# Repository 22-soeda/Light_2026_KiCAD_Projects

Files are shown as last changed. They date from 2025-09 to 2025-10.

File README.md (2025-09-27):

2026 ３月のROBO-ONE light 向けの回路CAD

工大祭(2025 11月頭)に向けて
 - main esp32e can
   - esp32とPCをwifiで接続して、GUIでロボットをデバッグ
   - Serial2をTTL変換して、zhコネクタで6ポート出力
   - 7.4VDCDC,12V 強電の系をまとめてスイッチング
   - canを2ポート搭載
   - 終端抵抗はブリッジで選択
   - BNO055はUART(Serial1)で実装
   - 5V reg, 3.3V DCDCを搭載
 - FSR to can
   - ATmega328P-AUをマイコンとする
   - 外部16MHz
   - FSRのシグナルをRail to Rail OPAMPで増幅、アナログ値を読み取り(4ポート)
   - MCP2515、MCP2561でcanを実装
   - 12V電源入力で、5Vregで降圧

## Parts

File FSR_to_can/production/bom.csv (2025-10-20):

Designator | Footprint | Quantity | Value | LCSC Part #
C1, C2 | 0805 | 2 | 0.1u
C3, C4 | 0805 | 2 | 1u
C5 | 0805 | 1 | 4.7u
C6 | 0805 | 1 | 10u
C7 | 0805 | 1 | 22u
C8 | 0805 | 1 | 0.1uF
D1 | 0603 | 1 | SCK
D2 | 0603 | 1 | power
J1 | JST_ZH_S5B-ZR-SM4A-TF_1x05-1MP_P1.50mm_Horizontal | 1 | FSR_socket
J2 | JST_ZH_B5B-ZR_1x05_P1.50mm_Vertical | 1 | write
J3 | JST_ZH_B6B-ZR_1x06_P1.50mm_Vertical | 1 | boot
J4 | JST_XH_S2B-XH-A_1x02_P2.50mm_Horizontal | 1 | power_socket
J5 | JST_ZH_S2B-ZR-SM4A-TF_1x02-1MP_P1.50mm_Horizontal | 1 | can_socket
JP1 | SolderJumper-2_P1.3mm_Open_RoundedPad1.0x1.5mm | 1 | Term
R1, R2, R3, R4, R5, R6, R7 | 0603 | 7 | 1k
R10, R11, R12, R9 | 0603 | 4 | R
R8 | 0603 | 1 | 120
SW1 | TVAF06-A020B-R | 1 | SW_Push
U1 | TQFP-32_7x7mm | 1 | ATMEGA328P-AU | ATMEGA328P-AU
U2 | SOT-223-3_TabPin2 | 1 | AMS1117-5.0
U3 | TSSOP-20_4.4x6.5mm_P0.65mm | 1 | MCP2515-xST
U4 | SOIC-8_3.9x4.9mm_P1.27mm | 1 | MCP2561-E-SN
U5, U6 | SOIC-8_W3.9mm | 2 | LMV358IDR | LMV358IDR
Y1 | Resonator_SMD_Murata_CSTxExxV-3Pin_3.0x1.1mm_HandSoldering | 1 | 16MHz
Y2 | Resonator_SMD_Murata_CSTxExxV-3Pin_3.0x1.1mm_HandSoldering | 1 | 8MHz

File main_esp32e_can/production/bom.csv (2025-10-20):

Designator | Footprint | Quantity | Value | LCSC Part #
C1 | 0805 | 1 | 22u
C10 | CP_Elec_6.3x5.9 | 1 | 100u
C11 | CP_Elec_5x5.8 | 1 | 10u
C12 | CP_Elec_6.3x5.9 | 1 | 22u
C13, C18 | 0805 | 2 | 10u
C14, C16, C19, C2, C21, C3, C4, C5, C6, C9 | 0805 | 10 | 0.1u
C15, C20 | 0805 | 2 | 33u
C17, C22 | 0805 | 2 | 47u
C7 | CP_Elec_10x12.6 | 1 | 470u
C8 | 0805 | 1 | 0.33u
D1 | 0603 | 1 | LED_motor
D2 | 0603 | 1 | LED_logic
J1 | JST_ZH_B6B-ZR_1x06_P1.50mm_Vertical | 1 | write_socket
J10, J11 | JST_XA_B02B-XASK-1_1x02_P2.50mm_Vertical | 2 | 12Vout
J12 | AMASS_XT60-M_1x02_P7.20mm_Vertical | 1 | Batt_socket
J13 | JST_XA_B02B-XASK-1-A_1x02_P2.50mm_Vertical | 1 | SW_strong
J14 | JST_XH_B2B-XH-AM_1x02_P2.50mm_Vertical | 1 | LED_strong
J15 | JST_XH_B2B-XH-AM_1x02_P2.50mm_Vertical | 1 | LED_logic
J16 | JST_XA_B02B-XASK-1-A_1x02_P2.50mm_Vertical | 1 | SW_logic
J2, J3, J4, J5 | JST_ZH_B3B-ZR_1x03_P1.50mm_Vertical | 4 | ICS_socket
J6, J7 | JST_ZH_B3B-ZR_1x03_P1.50mm_Vertical | 2 | 7V4
J8, J9 | JST_ZH_B2B-ZR_1x02_P1.50mm_Vertical | 2 | can_socket
JP1 | SolderJumper-2_P1.3mm_Open_RoundedPad1.0x1.5mm | 1 | Term
L1 | CM2021Y330R | 1 | CM2021Y330R
L2, L3 | L_Bourns-SRN8040_8x8.15mm | 2 | 4.7u
Q1, Q10, Q2, Q5, Q8, Q9 | SOT-23 | 6 | 2N7002K
Q3, Q4 | SOT-23 | 2 | 2SC2712
Q6, Q7 | TO-252-2 | 2 | TJ60S04M3L
R1, R10, R16, R20, R27, R29, R9 | 0603 | 7 | 10k
R11, R12, R6 | 0603 | 3 | 350
R13, R15, R17, R21, R4, R7 | 0603 | 6 | 120
R14, R19, R22, R23, R24, R25, R30, R31, R5, R8 | 0603 | 10 | 1k
R18, R2, R3 | 0603 | 3 | 2k
R26, R28 | 0603 | 2 | 30.9k
SW1 | SW_SPST_B3S-1000 | 1 | RESET
SW2 | SW_SPST_B3S-1000 | 1 | BOOT
U1 | BNO055_module | 1 | BNO055_module
U10, U11 | SOT-583-8 | 2 | TPS62933
U2 | ESP32-WROOM-32D | 1 | ESP32-WROOM-32E
U3, U4, U5 | SOIC-6-5_W4.55mm | 3 | TLP2361_TPL_E | TLP2361(TPL,E
U6 | VSSOP-8_2.3x2mm_P0.5mm | 1 | 74LVC2G241
U7 | SOIC-8_3.9x4.9mm_P1.27mm | 1 | MCP2561-E-SN
U8 | SOT-89-3 | 1 | L78L05_SOT89
U9 | SOT-223-3_TabPin2 | 1 | AMS1117-5.0

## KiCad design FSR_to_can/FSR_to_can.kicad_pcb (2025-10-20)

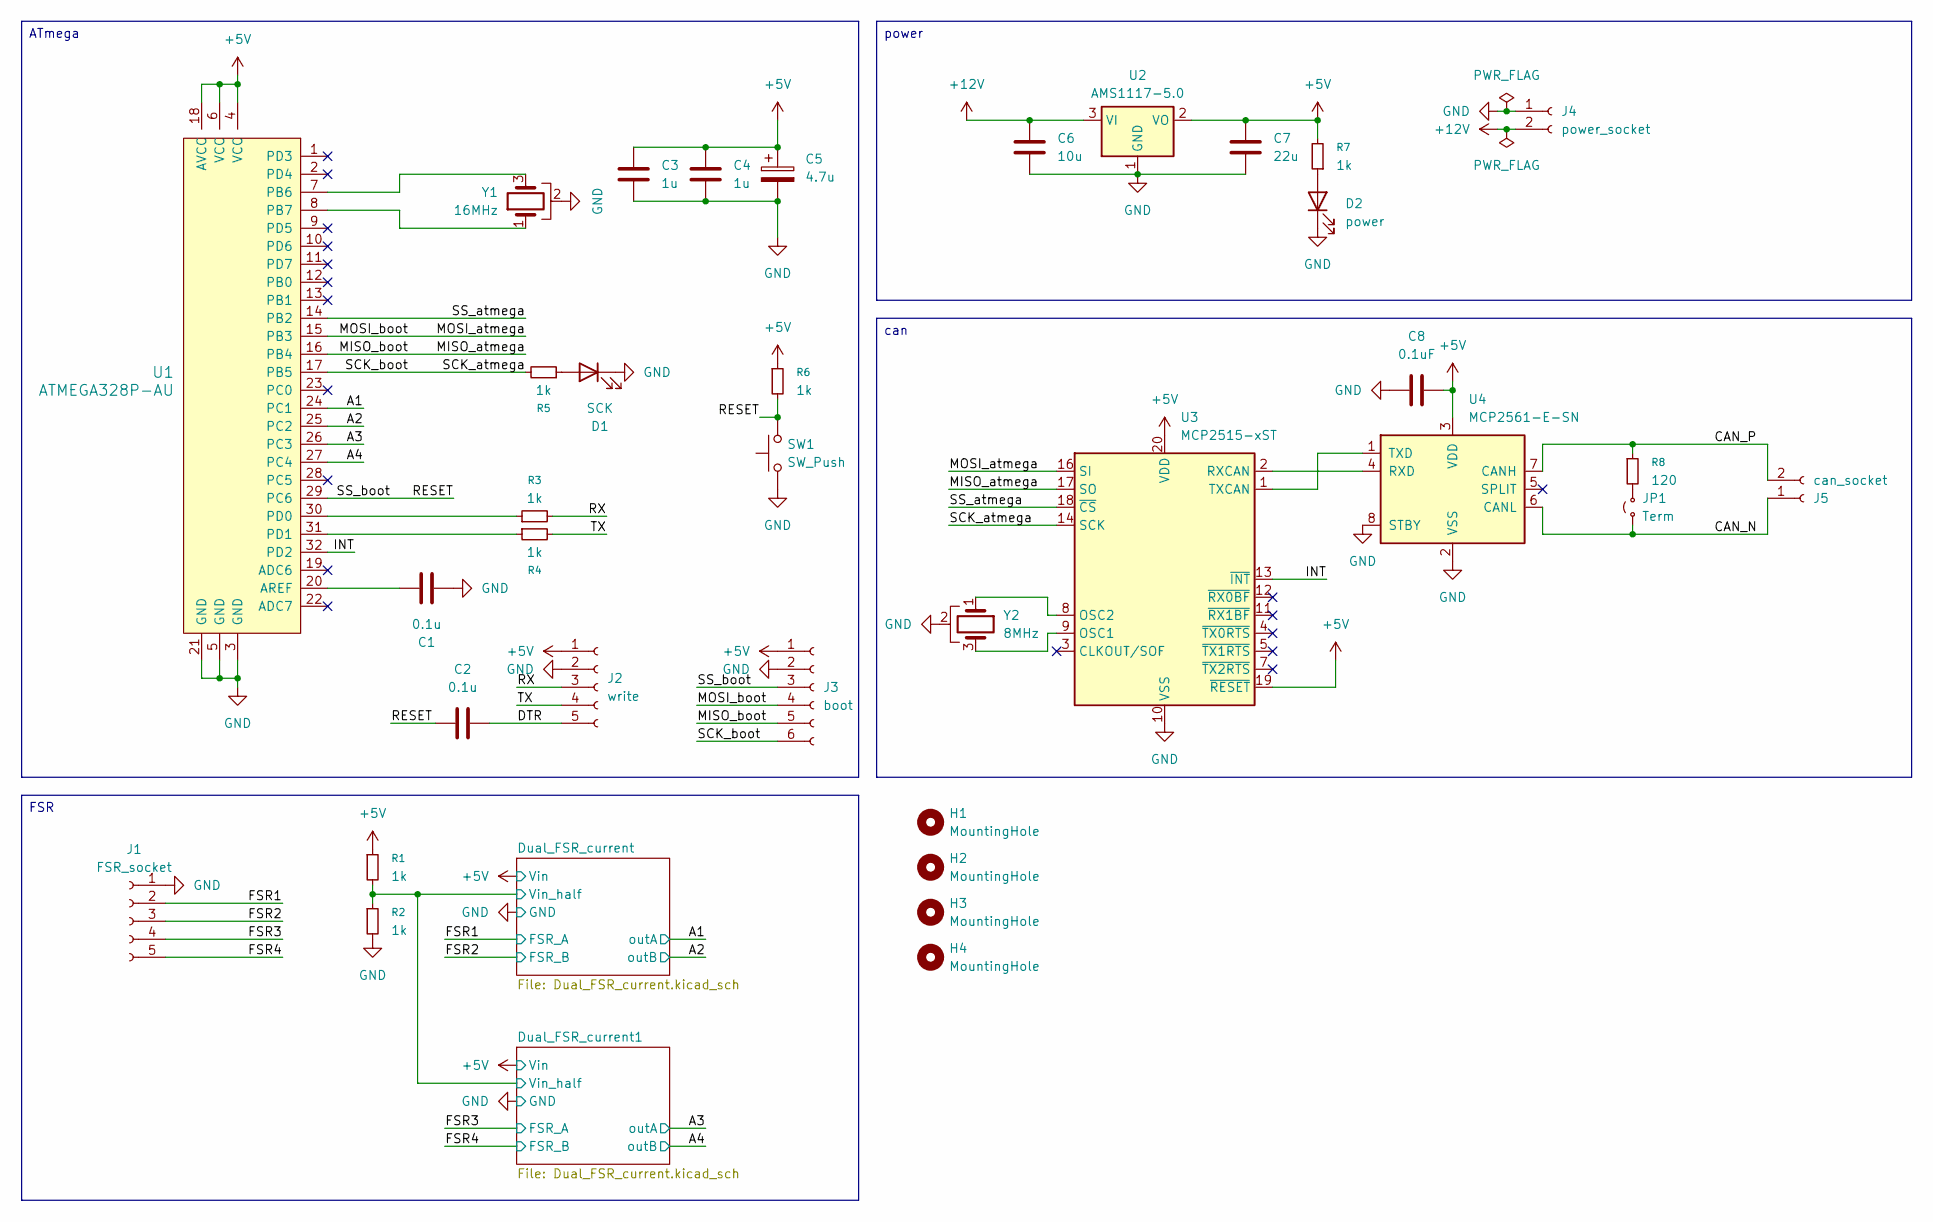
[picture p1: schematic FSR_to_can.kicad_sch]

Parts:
C1, C2: 0.1u; C_0805_2012Metric
C3, C4: 1u; C_0805_2012Metric
C5: 4.7u; C_0805_2012Metric
C6: 10u; C_0805_2012Metric
C7: 22u; C_0805_2012Metric
C8: 0.1uF; C_0805_2012Metric
D1: SCK; LED_0603_1608Metric_Pad1.05x0.95mm_HandSolder
D2: power; LED_0603_1608Metric_Pad1.05x0.95mm_HandSolder
H1, H2, H3, H4: MountingHole; MountingHole_2.2mm_M2_ISO14580
J1: FSR_socket; JST_ZH_S5B-ZR-SM4A-TF_1x05-1MP_P1.50mm_Horizontal
J2: write; JST_ZH_B5B-ZR_1x05_P1.50mm_Vertical
J3: boot; JST_ZH_B6B-ZR_1x06_P1.50mm_Vertical
J4: power_socket; JST_XH_S2B-XH-A_1x02_P2.50mm_Horizontal
J5: can_socket; JST_ZH_S2B-ZR-SM4A-TF_1x02-1MP_P1.50mm_Horizontal
JP1: Term; SolderJumper-2_P1.3mm_Open_RoundedPad1.0x1.5mm
R1, R2, R3, R4, R5, R6, R7: 1k; R_0603_1608Metric
R8: 120; R_0603_1608Metric
SW1: SW_Push; TVAF06-A020B-R
U1: ATMEGA328P-AU; TQFP-32_7x7mm; MPN ATMEGA328P-AU; Digi-Key_PN ATMEGA328P-AU-ND
U2: AMS1117-5.0; SOT-223-3_TabPin2
U3: MCP2515-xST; TSSOP-20_4.4x6.5mm_P0.65mm
U4: MCP2561-E-SN; SOIC-8_3.9x4.9mm_P1.27mm
Y1: 16MHz; Resonator_SMD_Murata_CSTxExxV-3Pin_3.0x1.1mm_HandSoldering
Y2: 8MHz; Resonator_SMD_Murata_CSTxExxV-3Pin_3.0x1.1mm_HandSoldering

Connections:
+5V: C3.1, C4.1, C5.1, C7.1, C8.1, J2.1, J3.1, R1.1, R6.1, R7.2, U1.4 (VCC), U1.6 (VCC), U1.18 (AVCC), U2.2 (VO), U3.19 (~RESET), U3.20 (VDD), U4.3 (VDD); also elsewhere on the board
+12V: C6.1, J4.2, U2.3 (VI)
/A1: U1.24 (PC1); also elsewhere on the board
/A2: U1.25 (PC2); also elsewhere on the board
/A3: U1.26 (PC3); also elsewhere on the board
/A4: U1.27 (PC4); also elsewhere on the board
/CAN_N: J5.1, JP1.1 (A), U4.6 (CANL)
/CAN_P: J5.2, R8.1, U4.7 (CANH)
/DTR: C2.2, J2.5
/Dual_FSR_current/Vin_half: R1.2, R2.1; also elsewhere on the board
/FSR1: J1.2; also elsewhere on the board
/FSR2: J1.3; also elsewhere on the board
/FSR3: J1.4; also elsewhere on the board
/FSR4: J1.5; also elsewhere on the board
/INT: U1.32 (PD2), U3.13 (~INT)
/MISO_atmega: J3.5, U1.16 (PB4), U3.17 (SO)
/MOSI_atmega: J3.4, U1.15 (PB3), U3.16 (SI)
/RESET: C2.1, J3.3, R6.2, SW1.2, U1.29 (PC6)
/RX: J2.3, R3.2
/SCK_atmega: J3.6, R5.2, U1.17 (PB5), U3.14 (SCK)
/SS_atmega: U1.14 (PB2), U3.18 (~CS)
/TX: J2.4, R4.2
GND: C1.2, C3.2, C4.2, C5.2, C6.2, C7.2, C8.2, D1.1 (K), D2.1 (K), J1.1, J2.2, J3.2, J4.1, R2.2, SW1.1, U1.3 (GND), U1.5 (GND), U1.21 (GND), U2.1 (GND), U3.10 (VSS), U4.2 (VSS), U4.8 (STBY), Y1.2, Y2.2; also elsewhere on the board
unnamed: D1.2 (A), R5.1
unnamed: D2.2 (A), R7.1
unnamed: JP1.2 (B), R8.2
unnamed: C1.1, U1.20 (AREF)
unnamed: U1.7 (PB6), Y1.3
unnamed: U1.8 (PB7), Y1.1
unnamed: R3.1, U1.30 (PD0)
unnamed: R4.1, U1.31 (PD1)
unnamed: U3.9 (OSC1), Y2.3
unnamed: U3.8 (OSC2), Y2.1
unnamed: U3.2 (RXCAN), U4.4 (RXD)
unnamed: U3.1 (TXCAN), U4.1 (TXD)

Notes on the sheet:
ATmega
FSR
power
can

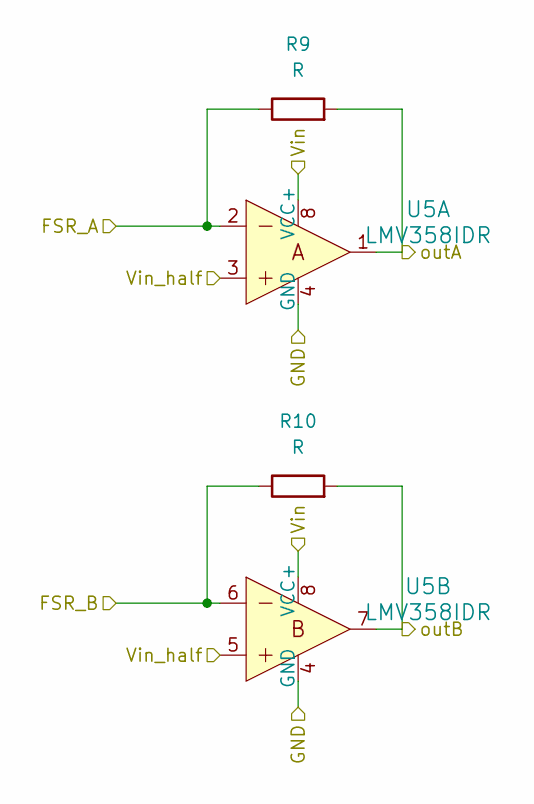
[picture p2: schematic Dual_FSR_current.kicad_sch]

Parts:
R9, R10: R; R_0603_1608Metric
U5: LMV358IDR; SOIC-8_W3.9mm; MPN LMV358IDR; Digi-Key_PN 296-9571-1-ND

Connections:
+5V: U5.8 (VCC+); also elsewhere on the board
/A1: R9.2, U5.1; also elsewhere on the board
/A2: R10.2, U5.7; also elsewhere on the board
/Dual_FSR_current/Vin_half: U5.3, U5.5; also elsewhere on the board
/FSR1: R9.1, U5.2; also elsewhere on the board
/FSR2: R10.1, U5.6; also elsewhere on the board
GND: U5.4 (GND); also elsewhere on the board

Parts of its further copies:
R11, R12: R; R_0603_1608Metric
U6: LMV358IDR; SOIC-8_W3.9mm; MPN LMV358IDR; Digi-Key_PN 296-9571-1-ND

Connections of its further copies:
+5V: U6.8 (VCC+); also elsewhere on the board
/A3: R11.2, U6.1; also elsewhere on the board
/A4: R12.2, U6.7; also elsewhere on the board
/Dual_FSR_current/Vin_half: U6.3, U6.5; also elsewhere on the board
/FSR3: R11.1, U6.2; also elsewhere on the board
/FSR4: R12.1, U6.6; also elsewhere on the board
GND: U6.4 (GND); also elsewhere on the board

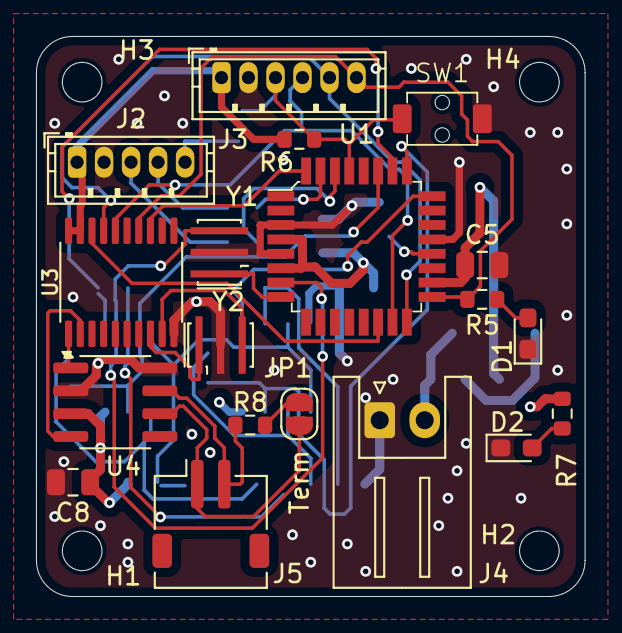
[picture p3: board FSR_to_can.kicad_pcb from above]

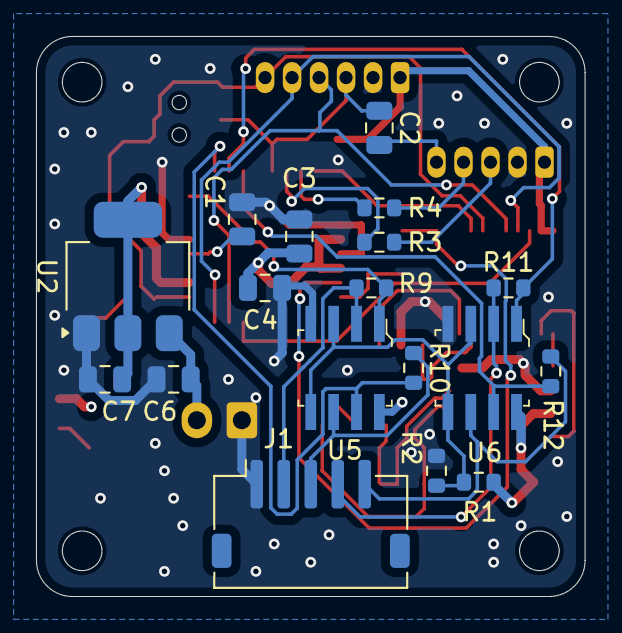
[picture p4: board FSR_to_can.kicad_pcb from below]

Board: 4 copper layers, 30.5 x 31.1 mm, 41 parts (18 on the bottom side), 35 nets.

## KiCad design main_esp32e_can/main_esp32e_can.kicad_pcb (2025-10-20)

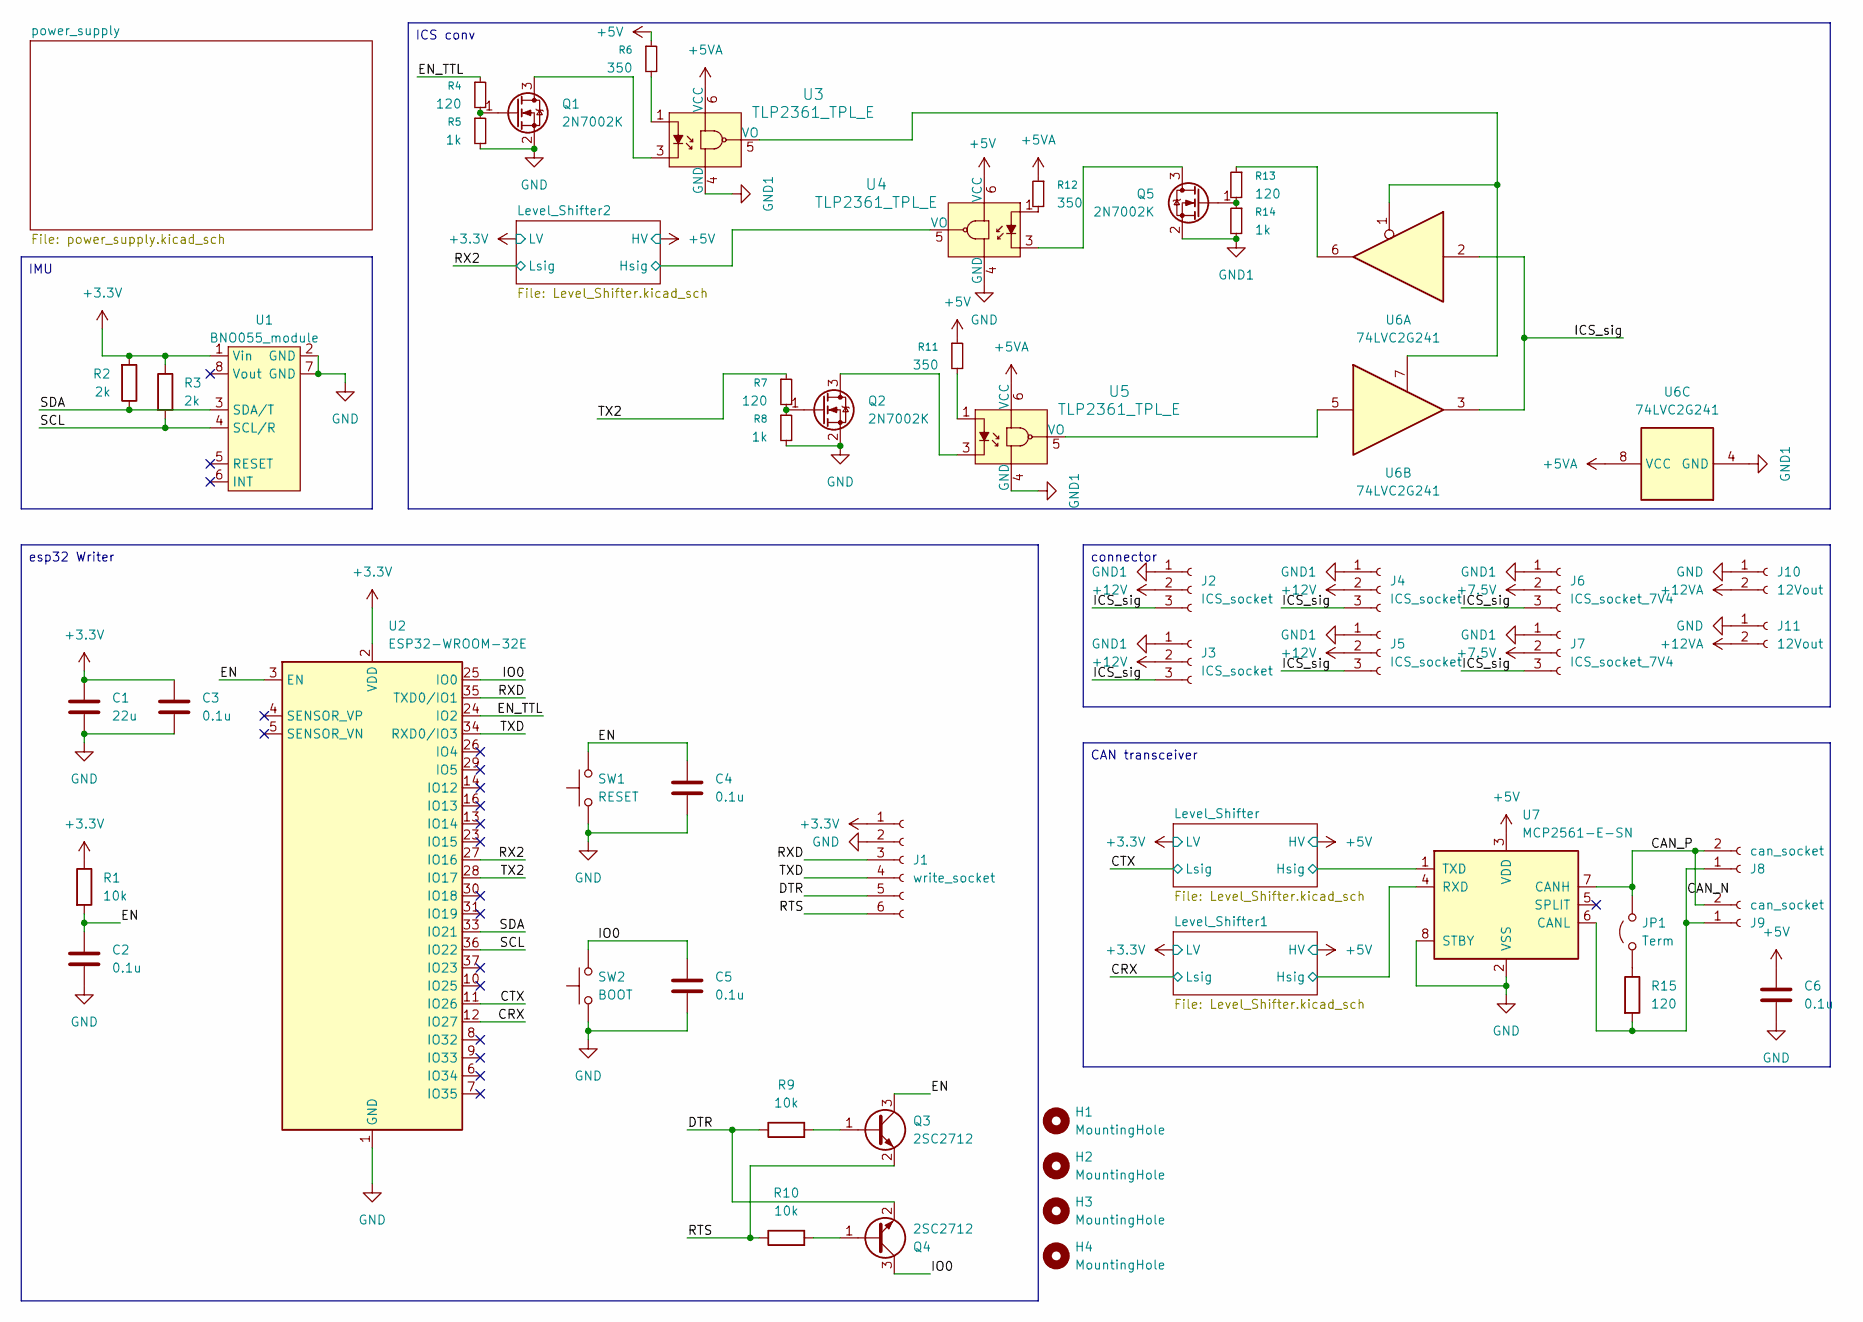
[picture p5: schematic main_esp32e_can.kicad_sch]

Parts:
C1: 22u; C_0805_2012Metric
C2, C3, C4, C5, C6: 0.1u; C_0805_2012Metric
H1, H2, H3, H4: MountingHole; MountingHole_3.2mm_M3
J1: write_socket; JST_ZH_B6B-ZR_1x06_P1.50mm_Vertical
J2, J3, J4, J5: ICS_socket; JST_ZH_B3B-ZR_1x03_P1.50mm_Vertical
J6, J7: ICS_socket_7V4; JST_ZH_B3B-ZR_1x03_P1.50mm_Vertical
J8, J9: can_socket; JST_ZH_B2B-ZR_1x02_P1.50mm_Vertical
J10, J11: 12Vout; JST_XA_B02B-XASK-1_1x02_P2.50mm_Vertical
JP1: Term; SolderJumper-2_P1.3mm_Open_RoundedPad1.0x1.5mm
Q1, Q2, Q5: 2N7002K; SOT-23
Q3, Q4: 2SC2712; SOT-23
R1, R9, R10: 10k; R_0603_1608Metric
R2, R3: 2k; R_0603_1608Metric
R4, R7, R13, R15: 120; R_0603_1608Metric
R5, R8, R14: 1k; R_0603_1608Metric
R6, R11, R12: 350; R_0603_1608Metric
SW1: RESET; SW_SPST_B3S-1000
SW2: BOOT; SW_SPST_B3S-1000
U1: BNO055_module
U2: ESP32-WROOM-32E; ESP32-WROOM-32D
U3, U4, U5: TLP2361_TPL_E; SOIC-6-5_W4.55mm; MPN TLP2361(TPL,E; Digi-Key_PN TLP2361(TPLECT-ND
U6: 74LVC2G241; VSSOP-8_2.3x2mm_P0.5mm
U7: MCP2561-E-SN; SOIC-8_3.9x4.9mm_P1.27mm

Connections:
+3.3V: C1.1, C3.1, J1.1, R1.1, R2.2, R3.1, U1.1 (Vin), U2.2 (VDD); also elsewhere on the board
+5V: C6.1, R6.1, R11.1, U4.6 (VCC), U7.3 (VDD); also elsewhere on the board
+5VA: R12.1, U3.6 (VCC), U5.6 (VCC), U6.8 (VCC); also elsewhere on the board
+7.5V: J6.2, J7.2; also elsewhere on the board
+12V: J2.2, J3.2, J4.2, J5.2; also elsewhere on the board
+12VA: J10.2, J11.2; also elsewhere on the board
/CAN_N: J8.1, J9.1, R15.2, U7.6 (CANL)
/CAN_P: J8.2, J9.2, JP1.2 (B), U7.7 (CANH)
/CRX: U2.12 (IO27); also elsewhere on the board
/CTX: U2.11 (IO26); also elsewhere on the board
/DTR: J1.5, Q4.2 (E), R9.1
/EN: C2.1, C4.1, Q3.3 (C), R1.2, SW1.2, U2.3 (EN)
/EN_TTL: R4.1, U2.24 (IO2)
/ICS_sig: J2.3, J3.3, J4.3, J5.3, J6.3, J7.3, U6.2, U6.3
/IO0: C5.1, Q4.3 (C), SW2.2, U2.25 (IO0)
/Level_Shifter1/Hsig: U7.4 (RXD); also elsewhere on the board
/Level_Shifter2/Hsig: U4.5 (VO); also elsewhere on the board
/Level_Shifter/Hsig: U7.1 (TXD); also elsewhere on the board
/RTS: J1.6, Q3.2 (E), R10.1
/RX2: U2.27 (IO16); also elsewhere on the board
/RXD: J1.3, U2.35 (TXD0/IO1)
/SCL: R3.2, U1.4 (SCL/R), U2.36 (IO22)
/SDA: R2.1, U1.3 (SDA/T), U2.33 (IO21)
/TX2: R7.1, U2.28 (IO17)
/TXD: J1.4, U2.34 (RXD0/IO3)
GND: C1.2, C2.2, C3.2, C4.2, C5.2, C6.2, J1.2, J10.1, J11.1, Q1.2 (S), Q2.2 (S), R5.2, R8.2, SW1.1, SW2.1, U1.2 (GND), U1.7 (GND), U2.1 (GND), U2.15 (GND), U2.38 (GND), U2.39 (GND), U4.4 (GND), U7.2 (VSS), U7.8 (STBY); also elsewhere on the board
GND1: J2.1, J3.1, J4.1, J5.1, J6.1, J7.1, Q5.2 (S), R14.2, U3.4 (GND), U5.4 (GND), U6.4 (GND); also elsewhere on the board
unnamed: JP1.1 (A), R15.1
unnamed: Q1.3 (D), U3.3
unnamed: Q1.1 (G), R4.2, R5.1
unnamed: Q2.3 (D), U5.3
unnamed: Q2.1 (G), R7.2, R8.1
unnamed: Q3.1 (B), R9.2
unnamed: Q4.1 (B), R10.2
unnamed: Q5.3 (D), U4.3
unnamed: Q5.1 (G), R13.2, R14.1
unnamed: R6.2, U3.1
unnamed: R11.2, U5.1
unnamed: R12.2, U4.1
unnamed: R13.1, U6.6
unnamed: U3.5 (VO), U6.1, U6.7
unnamed: U5.5 (VO), U6.5

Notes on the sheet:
esp32 Writer
ICS conv
CAN transceiver
IMU
connector

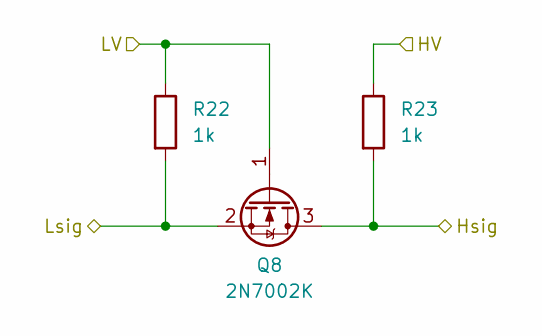
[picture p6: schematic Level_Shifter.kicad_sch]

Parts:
Q8: 2N7002K; SOT-23
R22, R23: 1k; R_0603_1608Metric

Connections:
+3.3V: Q8.1 (G), R22.1; also elsewhere on the board
+5V: R23.1; also elsewhere on the board
/CTX: Q8.2 (S), R22.2; also elsewhere on the board
/Level_Shifter/Hsig: Q8.3 (D), R23.2; also elsewhere on the board

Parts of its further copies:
Q9, Q10: 2N7002K; SOT-23
R24, R25, R30, R31: 1k; R_0603_1608Metric

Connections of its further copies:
+3.3V: Q9.1 (G), Q10.1 (G), R24.1, R30.1; also elsewhere on the board
+5V: R25.1, R31.1; also elsewhere on the board
/CRX: Q9.2 (S), R24.2; also elsewhere on the board
/Level_Shifter1/Hsig: Q9.3 (D), R25.2; also elsewhere on the board
/Level_Shifter2/Hsig: Q10.3 (D), R31.2; also elsewhere on the board
/RX2: Q10.2 (S), R30.2; also elsewhere on the board

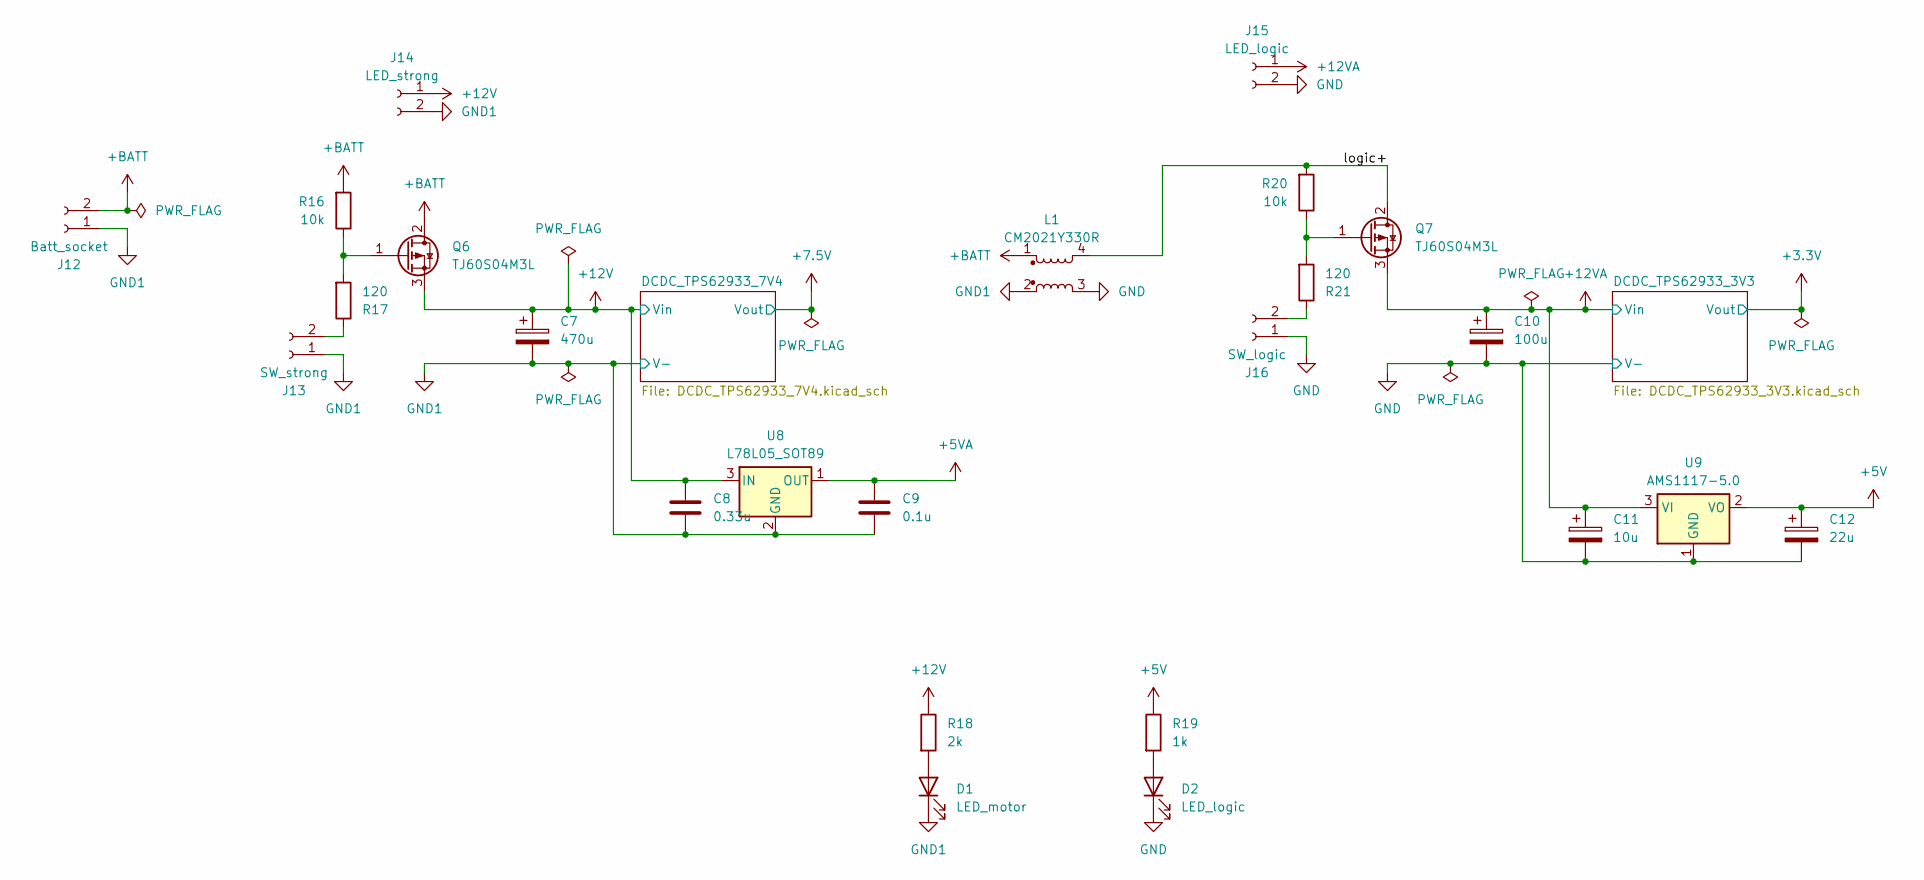
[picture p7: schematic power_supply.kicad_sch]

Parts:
C7: 470u; CP_Elec_10x12.6
C8: 0.33u; C_0805_2012Metric
C9: 0.1u; C_0805_2012Metric
C10: 100u; CP_Elec_6.3x5.9
C11: 10u; CP_Elec_5x5.8
C12: 22u; CP_Elec_6.3x5.9
D1: LED_motor; C_0603_1608Metric
D2: LED_logic; C_0603_1608Metric
J12: Batt_socket; AMASS_XT60-M_1x02_P7.20mm_Vertical
J13: SW_strong; JST_XA_B02B-XASK-1-A_1x02_P2.50mm_Vertical
J14: LED_strong; JST_XH_B2B-XH-AM_1x02_P2.50mm_Vertical
J15: LED_logic; JST_XH_B2B-XH-AM_1x02_P2.50mm_Vertical
J16: SW_logic; JST_XA_B02B-XASK-1-A_1x02_P2.50mm_Vertical
L1: CM2021Y330R
Q6, Q7: TJ60S04M3L; TO-252-2
R16, R20: 10k; R_0603_1608Metric
R17, R21: 120; R_0603_1608Metric
R18: 2k; R_0603_1608Metric
R19: 1k; R_0603_1608Metric
U8: L78L05_SOT89; SOT-89-3
U9: AMS1117-5.0; SOT-223-3_TabPin2

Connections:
+5V: C12.1, R19.1, U9.2 (VO); also elsewhere on the board
+5VA: C9.1, U8.1 (OUT); also elsewhere on the board
+12V: C7.1, C8.1, J14.1, Q6.3 (S), R18.1, U8.3 (IN); also elsewhere on the board
+12VA: C10.1, C11.1, J15.1, Q7.3 (S), U9.3 (VI); also elsewhere on the board
+BATT: J12.2, L1.1, Q6.2 (D), R16.2
/power_supply/logic+: L1.4, Q7.2 (D), R20.2
GND: C10.2, C11.2, C12.2, D2.1 (K), J15.2, J16.1, L1.3, U9.1 (GND); also elsewhere on the board
GND1: C7.2, C8.2, C9.2, D1.1 (K), J12.1, J13.1, J14.2, L1.2, U8.2 (GND); also elsewhere on the board
unnamed: D1.2 (A), R18.2
unnamed: D2.2 (A), R19.2
unnamed: J13.2, R17.1
unnamed: J16.2, R21.1
unnamed: Q6.1 (G), R16.1, R17.2
unnamed: Q7.1 (G), R20.1, R21.2

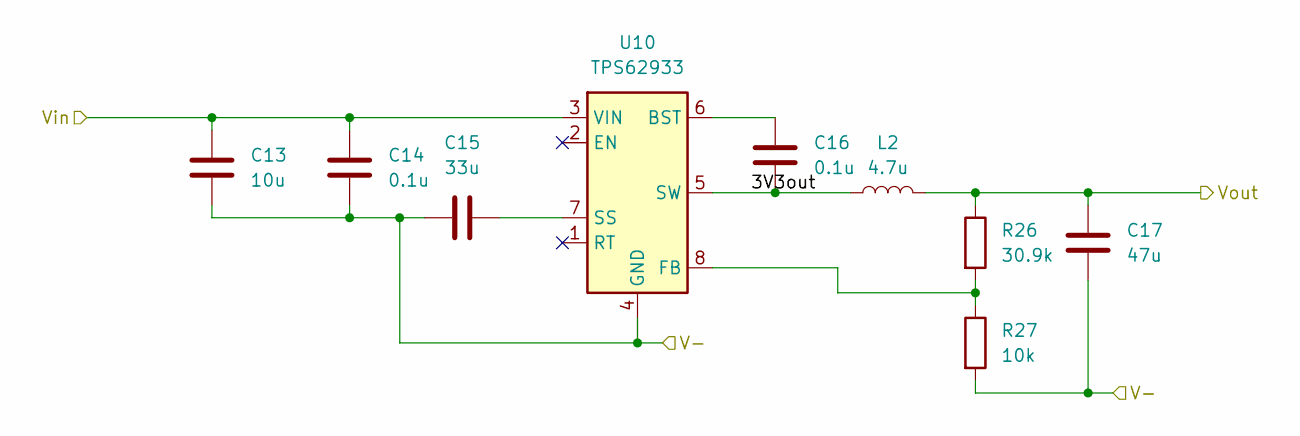
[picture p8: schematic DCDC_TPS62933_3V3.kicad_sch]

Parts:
C13: 10u; C_0805_2012Metric
C14, C16: 0.1u; C_0805_2012Metric
C15: 33u; C_0805_2012Metric
C17: 47u; C_0805_2012Metric
L2: 4.7u; L_Bourns-SRN8040_8x8.15mm
R26: 30.9k; R_0603_1608Metric
R27: 10k; R_0603_1608Metric
U10: TPS62933; SOT-583-8

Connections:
+3.3V: C17.1, L2.2, R26.1; also elsewhere on the board
+12VA: C13.1, C14.1, U10.3 (VIN); also elsewhere on the board
/power_supply/DCDC_TPS62933_3V3/3V3out: C16.2, L2.1, U10.5 (SW)
GND: C13.2, C14.2, C15.1, C17.2, R27.2, U10.4 (GND); also elsewhere on the board
unnamed: C16.1, U10.6 (BST)
unnamed: R26.2, R27.1, U10.8 (FB)
unnamed: C15.2, U10.7 (SS)

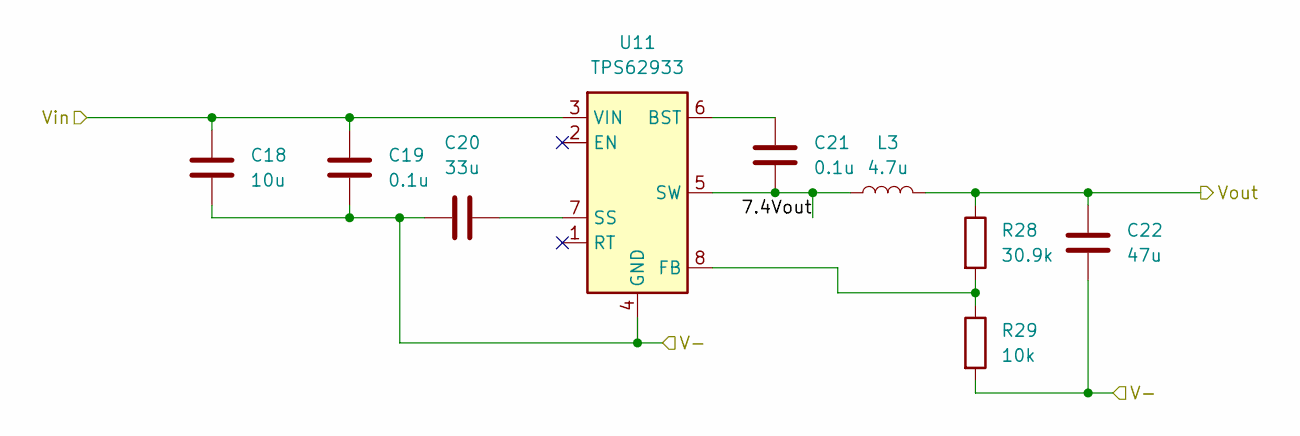
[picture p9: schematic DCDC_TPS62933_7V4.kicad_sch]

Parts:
C18: 10u; C_0805_2012Metric
C19, C21: 0.1u; C_0805_2012Metric
C20: 33u; C_0805_2012Metric
C22: 47u; C_0805_2012Metric
L3: 4.7u; L_Bourns-SRN8040_8x8.15mm
R28: 30.9k; R_0603_1608Metric
R29: 10k; R_0603_1608Metric
U11: TPS62933; SOT-583-8

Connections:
+7.5V: C22.1, L3.2, R28.1; also elsewhere on the board
+12V: C18.1, C19.1, U11.3 (VIN); also elsewhere on the board
/power_supply/DCDC_TPS62933_7V4/7.4Vout: C21.2, L3.1, U11.5 (SW)
GND1: C18.2, C19.2, C20.1, C22.2, R29.2, U11.4 (GND); also elsewhere on the board
unnamed: C21.1, U11.6 (BST)
unnamed: R28.2, R29.1, U11.8 (FB)
unnamed: C20.2, U11.7 (SS)

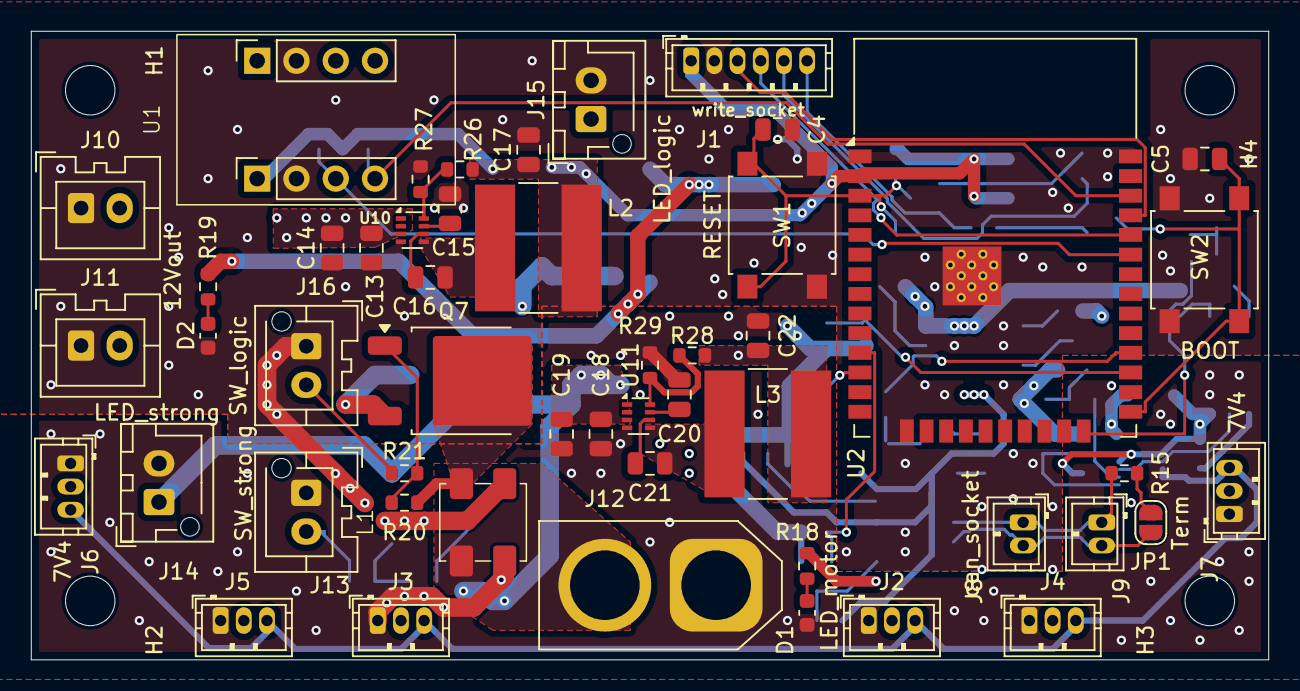
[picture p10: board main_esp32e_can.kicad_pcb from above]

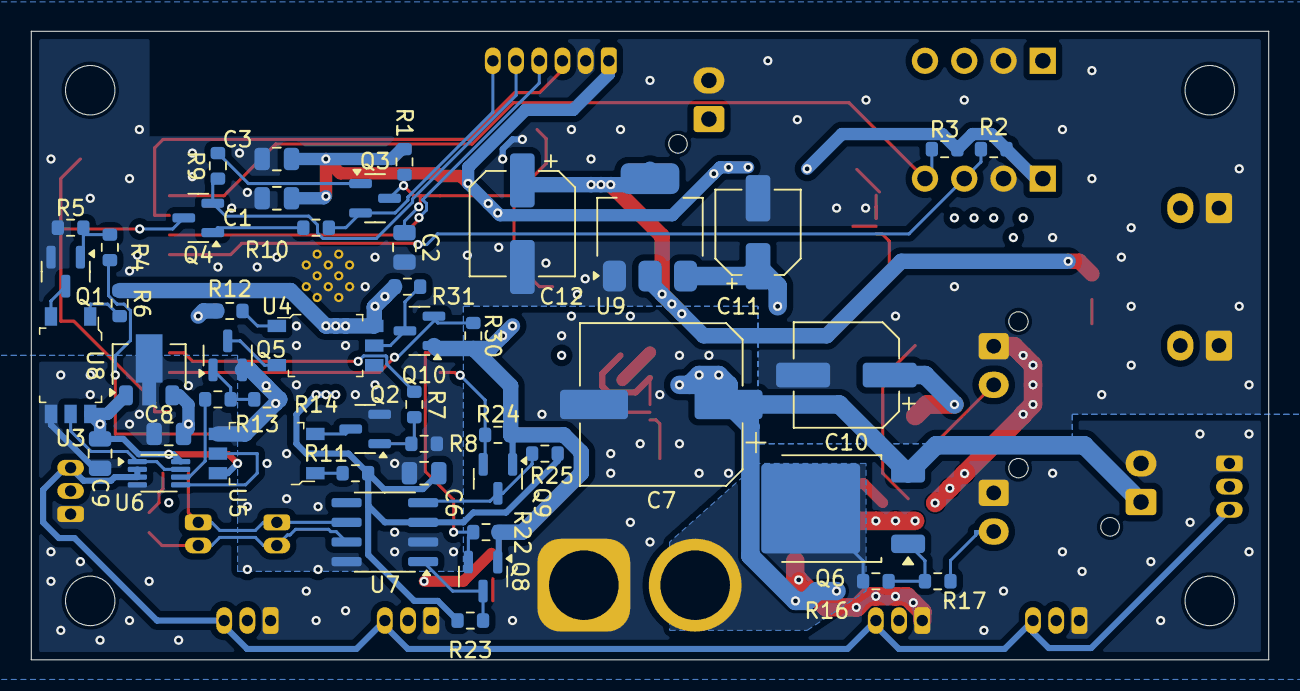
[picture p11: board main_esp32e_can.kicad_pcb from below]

Board: 4 copper layers, 80.0 x 40.6 mm, 102 parts (48 on the bottom side), 58 nets.
